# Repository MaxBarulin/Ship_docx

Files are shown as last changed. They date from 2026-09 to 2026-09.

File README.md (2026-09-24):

# «Волжский Горизонт» - колёсное круизное судно мелкой осадки

Проект под конкурсное задание УЖЦ ОСК 2026, редакция 2. Прототип по
технике - ПКС-180 «Золотое кольцо» (колёса в нишах, две жилые палубы);
внешность своя, современная: чёрный корпус, светлая лента главной палубы,
красная линия, графитовый ярус кают.

**Главное правило репозитория:** все числа проекта живут в параметрических
библиотеках `src/lib/`, вся графика и документы собираются скриптами из
`scripts/`. Если число встречается в записке или на плане - оно посчитано,
не набрано. Нашли расхождение между своим документом и библиотекой - права
библиотека; нужна правка - говорите Максу, а не правьте сгенерированный файл.

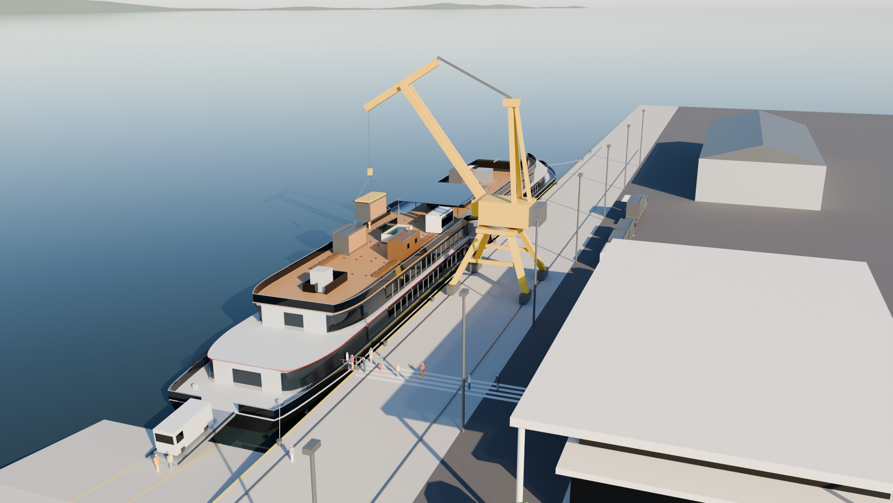
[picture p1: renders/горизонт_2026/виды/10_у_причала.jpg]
Порт приписки: смена модуля краном, сход по трапу и аппарели


---

## 1. Первый час - всем, по порядку

| # | Что открыть | Зачем | Время |
|---|---|---|---|
| 1 | [`renders/горизонт_2026/лист_проекта_горизонт.png`](renders/горизонт_2026/лист_проекта_горизонт.png), папка [`renders/горизонт_2026/виды/`](renders/горизонт_2026/виды/) | как судно выглядит: общий вид, борт, солнечная палуба с модулями, у причала | 5 мин |
| 2 | этот README, разделы 2 и 3 | что должен знать каждый и что смотреть именно вам | 10 мин |
| 3 | [`docs/проект/концепция.md`](docs/проект/концепция.md) | почему судно такое: каждое решение с причиной - это ответы на вопросы жюри | 15 мин |
| 4 | [`docs/сводка_состояние.md`](docs/сводка_состояние.md) | что закрыто по КЗ (15 требований) и по матрице оценки, что открыто по строкам - генерируется | 10 мин |
| 5 | [`docs/проект/записка.md`](docs/проект/записка.md) - оглавление и свой раздел | пояснительная записка по десяти блокам КЗ; незаполненные места помечены **НЕ ЗАПОЛНЕНО** | 10 мин |
| 6 | [`docs/задание/KZ_UZhTs_OSK_2026.md`](docs/задание/KZ_UZhTs_OSK_2026.md) и матрица `docs/задание/Zony_otvetsvennosti_2026_UZhTs.xlsx` | само задание и за что дают баллы | 10 мин |
| 7 | [`docs/план/План_работы_команды_УЖЦ_2026.md`](docs/план/План_работы_команды_УЖЦ_2026.md) | кто за что отвечает, гейты и синки | 5 мин |

## 2. Что должен знать каждый

| Характеристика | Значение |
|---|---|
| Длина × ширина корпуса | **140,0 × 16,5 м**; ширина задана маршрутом, длина - компоновкой |
| Габаритная ширина с колёсами | 16,0 м - колёса утоплены в ниши |
| Высота борта / осадка | 3,00 м / **1,26 м** при 2377 т (расчётная 1,30); КЗ: эксплуатация на глубине 1,5 м - 6,5 км/ч по мели |
| Габаритная высота от ВЛ | 9,9 м, рубка стационарная; самый низкий мост маршрута 13,3 м (Затонские мосты, Уфа) |
| Палубы | второе дно · трюм (нежилой, 2,1 м) · главная · средняя · солнечная (открытая) |
| Пассажиры / экипаж | **208 мест в 64 каютах** четырёх категорий, 12 мест М4 / 48 человек |
| Движитель | два гребных колеса Ø4,90 м на миделе, 12 шарнирных плиц, механизм Моргана |
| Энергетика | гибрид: 3 ГДГ по 600 кВт на **метаноле**, батарея 600 кВт·ч, берег, солнце; автономность 15 суток |
| Автомобили | 4 места класса «Б» до 3,5 т: гараж на главной палубе, кормовая аппарель 9 × 3,6 м |
| Сервисы сверх ресторанов | пять: театр-лаунж, спа и фитнес, детский клуб, панорамный салон, галереи к колёсам |
| Маршрут | кольцо Самара - Казань - Уфа - Самара по Волге, Каме и Белой, 15 дней, 2606 км; класс РКО «О 2,0» |
| Солнечная палуба | 18 слотов под контейнеры 20' HC на **72 фундаментах-замках**, шесть тем «трансформера» до 60 т (запас по заданию Глеба 85 т); смена темы - в Самаре краном порта |
| **Узел КД** | **литой фундамент-замок модуля ВГ-2026.46.00** - решение команды 22.09.2026 |

Решения, которые нельзя перепутать на защите:

- **Узел для КД - литой фундамент-замок** для крепления модулей солнечной
  палубы (решение 22.09.2026, он же по заданию Глеба). В плане команды §7
  ещё прежний узел - ось плицы; от него отказались, его документации в
  репозитории нет.
- **Фундамент литой, литейка своя**: корпус 20ГЛ литьём в форму из ХТС,
  конус-замок 40Х, рычаг 09Г2С, четыре болта М24 А4-80 через изолирующие
  втулки на подкладной лист АМг5. Нагрузки - от качки **этого** судна
  (период и крен - из теории корабля), а не из старого проекта.
- **Осадка:** расчётная 1,30, фактическая по нагрузке масс 1,26; узел
  считан на худший период качки в диапазоне осадок 1,20…1,30.
- **Метанол, а не СПГ:** танк СПГ не встаёт ни в трюм, ни под мосты;
  метанол - в цистернах второго дна, бункеровка автоцистерной на любом причале.
- **Смена модуля у причала** (`gorizont_berth`): судно лагом левым бортом,
  портальный кран 16 т достаёт дальний ряд на вылете 20,3 м; трап и
  аппарель не круче 0,08 - проходимы для кресла-коляски.

## 3. Кому что смотреть первым делом

Роли - по плану команды. «Открыто» - строки матрицы, которые на 22.09 не
закрыты; живой список - `docs/сводка_состояние.md`, раздел 4.

| Кто | Роль по плану | Открыть первым | За вами открыто |
|---|---|---|---|
| **Владимир** | докладчик, чек-лист КЗ (C4) | `docs/сводка_состояние.md` §1 - все 15 требований КЗ сходятся, у каждого место; `python scripts/сверка_требований_КЗ.py` - чек-лист «требование → где закрыто»; `концепция.md` - ответы на «почему»; лист проекта и `виды/` | творческое задание - 5 мемов к 24.09 (2 балла, с Андреем); прогон регламента |
| **Маша** | интеграция, ПЗ, презентация, персонал, риски | `docs/проект/записка.md` целиком - она сводит; разделы 5 и 8; `docs/проект/персонал_и_дорожная_карта.md`; схемы `02б_загрузка_персонала.png`, `03_оргструктура.png`; `docs/команда/README.md` - что из ваших файлов встроено | записка 5.3…5.5 (подбор, оплата, обучение - 2,5); подтвердить оценки и мероприятия реестра рисков (3,5 частично); кооперация по судну (1,5); презентация (3,5); все разделы и вёрстка ПЗ в А4 (2); сквозная проверка «вход → выход» (2) |
| **Лена** | финмодель | записка раздел 6 и 5.3…5.5 - по вашей таблице (`docs/команда/Nash_raschet_shablon.xlsx`), приложение Б - `docs/проект/приложение_Б_экономика.xlsx`, что поправлено - `gorizont_economy.ПРАВКИ`; входы для затрат: трудоёмкость и численность - `персонал_и_дорожная_карта.md`; спецификация узла - `renders/горизонт_2026/чертежи/46_спецификация_лист1…2.png`; мощности, оборудование и программа выпуска узла - `docs/проект/узел_фундамент_twistlock.md` §7…10; нагрузка масс судна - `docs/проект/теория_корабля.md`, А.2 | затраты, себестоимость, цена, выручка, точка безубыточности, окупаемость, NPV/IRR, схема финансирования - около 19 баллов; ставки для `gorizont_build.затраты_на_персонал` |
| **Иван** | рынок, маршрут | записка 1.1 (1.1.2…1.1.5 пусты), 1.1.7 - сегменты уже посчитаны (`gorizont_market`); карта маршрута `схемы/04а_маршрут_карта.png`; замечания к «Маршрутам» - `gorizont_route.ЗАМЕЧАНИЯ` и концепция §8 | объём рынка, объём продаж, конкуренты, маркетинговая стратегия, цены и сеть для ППО - 5,5 балла; стоимость единицы на рынке - с Леной |
| **Глеб** | технология, материалы; модули солнечной палубы | `docs/проект/узел_фундамент_twistlock.md` - ваш «Чертёж крепления» стал узлом КД: материалы §3, литьё и подготовка формы §5, оснастка §6, мощности §7, планировка §9; карты ЕСТД `renders/горизонт_2026/чертежи/46_МК_*, 46_ОК*, 46_КЭ*, 46_ККИ*`; модульное решение - `docs/проект/модульное_решение.md`, листы `CAD/модули/МР-01…03`; кадр `виды/11_смена_модуля.jpg` | сверить принятое: оборудование литейки, загрузку цехов, планировку (2 балла частично); прислать остальные файлы «пачки» креплений - в репозитории только `Чертёж крепления.jpg` |
| **Андрей** | прочность, планировка участка | узел §4 - расчёт по качке судна, 44 проверки; теория корабля `docs/проект/теория_корабля.md` (остойчивость А.3, прочность А.7), листы `CAD/расчёты/РТ-01…09`; планировка `схемы/08_узел_участок.png` | творческое задание (с Владимиром); планировку сверить с цехами верфи |
| **Алексей** | КД узла, работоспособность идеи | СБ и детали: `CAD/узел/ВГ-2026_46_*.dxf` (растр - `renders/горизонт_2026/чертежи_dxf/ВГ-2026_46_*.png`); 3D - `CAD/STEP/VG-2026_46_*.step`; спецификация; рендеры `узел/46_01…03`; эксплуатация - записка раздел 9 | DWG листов узла - `CAD/DWG/узел/` (собраны 23.09); просмотреть КД глазами конструктора |
| **Макс** | 3D, визуализация | `CLAUDE.md` - как устроен репозиторий; `blender/gorizont.blend`; `scripts/blender_*` | взрыв-схема и лист проекта - пересобираются из скриптов; презентационные кадры для Маши |

## 4. Что открыто (43,5 балла из 95 по документам, на 22.09)

| Блок | Баллов | Кто | Что нужно |
|---|---|---|---|
| Экономика и затраты (A, B6) | ≈ 19 | Лена (+ Иван по цене) | финмодель целиком; входы уже есть в библиотеках (см. раздел 3) |
| Персонал: подбор, оплата, обучение (B6) | 2,5 | Маша | записка 5.3…5.5 |
| Риски и кооперация (B2) | 5 частично | Маша | подтвердить оценки реестра рисков; кооперация по судну |
| Рынок (B4) | 5,5 | Иван | записка 1.1.2…1.1.5 |
| Презентация и ПЗ (C1, C2) | 5,5 | Маша | презентация; вёрстка записки в А4 |
| Сквозная связность (B1) | 2 частично | Маша | «вход → выход» после заполнения записки |
| Творческое задание (A) | 2 | Андрей, Владимир | мемы к 24.09 |
| Мощности и планировка узла (B5) | 2 частично | Глеб, Андрей | сверить принятое оборудование и загрузку с данными верфи |

Закрыто 51,5 балла: концепция, дизайн-проект, КД узла, технология и
производство узла, теория корабля, чертежи ОР, модель и визуализация,
требования КЗ (C4).

## 5. Где что лежит

```
docs/задание/            КЗ ред. 2 и матрица оценки - не менять
docs/план/               план и Гант команды - не менять без просьбы
docs/команда/            ваши файлы как получены (байт в байт); что из них встроено - docs/команда/README.md
docs/проект/             концепция, записка, узел КД, модульное решение, теория корабля, персонал и дорожная карта
docs/сводка_состояние.md состояние по КЗ и матрице - генерируется scripts/сводка.py
src/lib/                 параметрические библиотеки: здесь живут все числа (карта - CLAUDE.md)
scripts/                 генераторы: модель, планы, схемы, чертежи, записки, сверки
CAD/                     ОР-01…08, РТ-01…09, МР-01…03, КД узла в DXF; DWG/ - те же в DWG; STEP/, GLB/ - 3D узла
renders/горизонт_2026/   виды, планы, схемы, расчёты, чертежи, узел, каюты, облик - генерируется
blender/gorizont.blend   модель судна с солнечной палубой; собирается с нуля blender_судно.собрать()
```

Картинки для презентации:

| Что | Где |
|---|---|
| судно целиком, борт, корма, нос, вид сверху | `renders/горизонт_2026/виды/01…08_*.jpg` |
| у причала, смена модуля, сход на берег | `renders/горизонт_2026/виды/10_у_причала.jpg`, `11_смена_модуля.jpg`, `12_сход_на_берег.jpg` |
| взрыв-схема судна | `renders/горизонт_2026/виды/09_взрыв_схема.jpg` |
| узел: сборка, взрыв-схема, отливка со стержнем | `renders/горизонт_2026/узел/46_01…03_*.png` |
| интерьеры кают | `renders/горизонт_2026/каюты/00_лист_кают.png` |
| планы палуб | `renders/горизонт_2026/планы/` |
| маршрут, дорожная карта, оргструктура, модули, производство узла | `renders/горизонт_2026/схемы/` |
| чертежи в растре | `renders/горизонт_2026/чертежи_dxf/`, `…/чертежи/` |

## 6. Как пересобрать и проверить

```bash
pip install -r requirements.txt
cd src && python -m lib.gorizont_ga && cd ..      # вместимость и проверки компоновки
python scripts/сверка_требований_КЗ.py             # требования КЗ и матрица оценки
python scripts/сводка.py                           # docs/сводка_состояние.md
python scripts/записка.py                          # docs/проект/записка.md
python scripts/записка_фундамента.py               # docs/проект/узел_фундамент_twistlock.md
```

Остальные проверки и сборка модели в Blender - `CLAUDE.md`.

## 7. Правила для всех

1. Числа - только из библиотек или сгенерированных документов; руками не переписывать.
2. Свои файлы - в `docs/команда/` как есть; Макс встроит их в библиотеки и
   допишет строку в `docs/команда/README.md`.
3. Сгенерированные файлы (`записка.md`, `сводка_состояние.md`, `теория_корабля.md`,
   `узел_фундамент_twistlock.md`, всё в `renders/`) руками не правятся:
   правка пропадёт при следующей сборке. Текст для записки - присылать,
   он встанет в скрипт.
4. `docs/задание/` не менять никогда; `docs/план/` - только по просьбе.

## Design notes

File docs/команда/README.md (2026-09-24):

# Файлы от команды — как получены

Лежат байт в байт (`.gitattributes`: `docs/команда/** -text`), не правятся.
Что из них встроено в проект и что в них надо поправить —
`docs/проект/персонал_и_дорожная_карта.md`; первичная сверка —
`docs/проект/сверка_персонал_и_дорожная_карта.md`.

| Файл | От кого | Получен | Что это | Куда встроено |
|---|---|---|---|---|
| `Raschet_chislennosti_PRIMER.docx` | Лена, Маша | 22.09.2026 | пример расчёта численности по Приказу Минпромторга № 958 на чужое судно 3283 т | методика в `src/lib/gorizont_build.трудоёмкость()`, `численность()`; считается на наше порожнее из `gorizont_hydro` |
| `Org_struktura.docx` | Маша | 22.09.2026 | схема оргструктуры верфи (SmartArt) и справка «проектное бюро или дочерняя компания» | `gorizont_build.оргструктура()` → `renders/горизонт_2026/схемы/03_оргструктура.png`; добавлены ПБ и служба качества с РРР |
| `UZhTs_Dorozhnaya_karta.pdf` | Маша | 22.09.2026 | дорожная карта постройки, первая редакция (MS Project, 42 задачи, 17.09.2026 — 29.09.2028) | заменена редакцией Лены; наши замечания к ней учтены там |
| `солнечная_палуба/` | Глеб | 22.09.2026 | задание по модульным решениям (`Информаци-задание.docx`: площадка 32 × 13 м, запас 85 т, пять тем из 20-футовых контейнеров, twistlock на болтах), 3D узла крепления (`Чертёж крепления.jpg`: платик 09Г2С, палец 40Х), референсы бань, бассейна, офисов и две страницы поставщиков модулей | `src/lib/gorizont_modules.py` → листы `CAD/модули/ВГ-2026_МР-01…03`, `docs/проект/модульное_решение.md`, `схемы/06_модульное_решение.png`; крепление стало **узлом КД** — литой фундамент-замок ВГ-2026.46.00 (`gorizont_twistlock`, `CAD/узел/`, `docs/проект/узел_фундамент_twistlock.md`); в модели — 72 опоры и модули темы, смена модуля у причала (`виды/11_смена_модуля.jpg`) |
| `Маршруты.docx` | маршрутная группа (Иван) | 22.09.2026 | маршрут, редакция 2: программа по дням (Набережные Челны + автобус в Елабугу, ходовой день на Белой) и таблица мостов по плечам с допустимыми высотами | `gorizont_route.ПОРТЫ`, `МОСТЫ` → `МОСТ_МИН` 13,3; замечания к файлу — `gorizont_route.ЗАМЕЧАНИЯ` и концепция §8; карта `схемы/04_маршрут.png`, `маршрут.geojson` |
| `Дорожная_карта_Лена.pdf` | Лена | 22.09.2026 14:56 | дорожная карта постройки, вторая редакция (52 задачи, 22.09.2026 — 22.05.2030, с РКД, Регистром, МТО и закладкой киля) | заменена третьей редакцией; наши четыре замечания к ней учтены там частично |
| `Дорожная_карта_Лена_ред3.pdf` | Лена | 22.09.2026 16:22 | третья редакция (55 задач, сдача 06.06.2030) | заменена четвёртой |
| `Дорожная_карта_Лена_ред4.pdf` | Лена | 23.09.2026 | четвёртая редакция (MS Project, 56 задач, 864 дня, закладка 08.12.2027, спуск 12.09.2028, ходовые 05.10.2029, передача 11.01.2030) | **база** `gorizont_build.ЛЕНА`, страницы как есть - `схемы/02а_дорожная_карта_стр1…2.png`; исправлена опечатка - сервис с 12.01.2030 (в карте 12.01.2035) |
| `Персонал_Маша.docx` | Маша | 23.09.2026 | раздел «Персонал» - оргструктура верфи и проектной группы, схема взаимодействия, расчёт численности по № 958, подбор, оплата труда | на обсуждении, в записку не встроен |
| `правки 23.09.26/ПЗ_УЖЦ_2026.docx` | Маша, Глеб | 23.09.2026 | ПЗ команды: **титульный лист Маши - идёт в записку как есть**; красным - технология узла Глеба (твистлок «ласточкин хвост» из 4 деталей, литьё поз. 1-3, плазма поз. 4, оборудование, две цепочки шагов) | `gorizont_twistlock` (технология, цех в арендованном ангаре, мощности, себестоимость), записка блок 4; остальной текст ПЗ - черновики, не брались |
| `правки 23.09.26/Корпус твистлока (модель, узел).m3d`, `.prt` | Андрей | 23.09.2026 | модель корпуса узла (КОМПАС-3D v22 и NX) | габарит 175 × 160 × 76 мм взят из JT внутри `.prt`; для 3D и чертежей нужен STEP |
| `правки 23.09.26/Корпус твистлока. Отчет 09г2с.html`, `... Отчет Вст3СП5.html` | Андрей | 23.09.2026 | расчёт МКЭ узла в APM FEM (сила 33,1 кН = бассейн 13,5 т на 4 опоры) | заменены отчётом 24.09 из папки `Прочность` |
| `Прочность/Отчет 20ГСЛ.html`, `20ГСЛ Коэф запаса.png`, `20ГСЛ Перемещение 1.png`, `... 2.png` | Андрей | 24.09.2026 | расчёт МКЭ узла в сборе на принятых материалах - корпус 20ГСЛ, платик 09Г2С, запор 40Х, 33,1 кН; запас 3,83 по текучести, 6,93 по прочности, 191,8 МПа, 0,0028 мм | берётся как есть: `gorizont_twistlock.МКЭ`, записка 3.3, 3.4, записка узла 4.2; картинки - рисунки 46_04…06 без дерева и окна КОМПАС (`записка_фундамента.рисунки_мкэ`) |
| `Маша (правки по тексту, очеловечивание).docx` | Маша | 24.09.2026 | новый текст введения, 1.1 абзацы 1-2, первый абзац сегмента рынка, 5.1 абзац 1 | вставлено: `записка.введение()`, `записка_рынок._анализ`, `gorizont_market.ПОЗИЦИОНИРОВАНИЕ` (он же в 1.1.7), `записка.блок5`. Поправлено: «–» и «;» по правилам, «В отличии» → «В отличие», «Новизной ... является в» → «Новизна ... заключается в», «наличие флота» → «нехватка флота», «пары преклонного возраста» → «старшего» (сегмент 45+), «заместитель» → «заместители», «службой» → «службы», «посадка и высадка на протяжении всего маршрута» → «маршрут кольцевой» |
| `Nash_raschet_shablon.xlsx` | Лена | 24.09.2026 | расчёт себестоимости постройки по статьям верфи: материалы, ПКИ, трудоёмкость, ФОТ, ДЗП, взносы, АУП и ИТР, обучение, маркетинг | `gorizont_economy`, записка блок 6 и 5.3…5.5, приложение Б (`docs/проект/приложение_Б_экономика.xlsx`); исправлены ТЗР, единицы кабеля и труб, металл по массе проекта, добавлены ОПР, ОХР, прибыль, НИОКР, безубыточность, окупаемость |
| `правки 23.09.26/Marketing.docx` | Иван | 23.09.2026 | анализ рынка, PEST, SWOT, сегменты, TAM/SAM/SOM, цены, конкуренты, 4P | `gorizont_market`, записка блок 1; пересчитано на 208 мест, 11 рейсов, навигацию май - октябрь, без балконов |

Числа проекта в документах коллег (водоизмещение, сроки, численность)
надо брать из библиотек, а не переписывать руками: см. таблицы сравнения в
`персонал_и_дорожная_карта.md`.

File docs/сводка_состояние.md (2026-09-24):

# Волжский Горизонт - состояние проекта

Собрано `scripts/сводка.py` из живых данных проекта. Руками здесь
не написано ни одного числа - всё считается библиотеками или читается
из файлов задания и из файловой системы.

## 0. Стадии - что сделано и что впереди

| Стадия | Статус | Где |
|---|---|---|
| 1. Проектирование - концепция, компоновка всех уровней, планы палуб и кают | **сделано** | docs/проект/концепция.md, renders/горизонт_2026/планы/ |
| 2. Визуальный концепт в 2D - борт, план, сечения, цвет | **принят (облик v2)** | renders/горизонт_2026/облик/, scripts/облик_2d.py |
| 3. Решения команды - длина 140, облегчённая конструкция, тип плиц, блок C4 | **приняты** | docs/проект/концепция.md, п. 6 |
| 4. Программа снижения массы - алюминий, лёгкая отделка, сталь D36, нагрузка масс по размещению | **сделано** | gorizont_hydro.groups() - трюм и цистерны из gorizont.ТРЮМ/TANKS, дифферент 0,11 м |
| 5а. Модель. Оболочка по облику v2 - корпус, палубы, ярусы, портал, колёса, фальшборты | **сделано** | blender_судно.собрать() - 0 пересечений, 0 щелей, 16,50 м |
| 5б. Модель. Наполнение - переборки, каюты с мебелью, трапы, лифты, трюм по gorizont.ТРЮМ | **сделано** | blender_помещения.py - 1219 объектов, 0 пересечений, 0 щелей |
| 5в. Модель - общественные помещения, проёмы переборок, колодцы трапов, навес модулей, фонарь атриума | **сделано** | src/lib/gorizont_public.py - один источник для планов, DXF и 3D, 6 проверок, в т. ч. путь эвакуации 1,2 м |
| 5г. Модель. Солнечная палуба - 72 фундамента-замка ВГ-2026.46.00 из 3D узла (закрыто под модулем, открыто на свободном слоте), модули темы «президентская» с отделкой по типу | **сделано** | blender_модули.py, входит в blender_судно.собрать(тема=…), 0 пересечений, 0 щелей |
| 5д. Стоянка у причала порта приписки - стенка, пандус под аппарель, трап, швартовы, портальный кран 16 т с модулем на крюке, кадры 10…12 | **сделано** | gorizont_berth (9 проверок - уклоны трапа и аппарели, вылет и груз крана, пронос над соседями), blender_причал.py |
| 6. Узел КД (решение команды 23.09.2026) - фундамент-замок модуля ВГ-2026.46.00, твистлок «ласточкин хвост» из 4 деталей - корпус 20ГСЛ по STEP конструктора, запор-поковка 40Х, стержень, платик 09Г2С, и шайба-подкова. Отчёт МКЭ конструктора на принятых материалах, качка судна, материалы, спецификация | **библиотека сделана, КД и 3D перестраиваются** | gorizont_twistlock (62 проверки, 0 замечаний, модули тяжелее 10 т только в ДП, фундамент 0,077 м в gorizont.py), docs/проект/узел_фундамент_twistlock.md. CAD/узел/, CAD/STEP, GLB, рендеры узла - прежнего литого узла |
| 7. Технология и производство узла - отдельный цех в арендованном ангаре 36 × 24: литейная ветка (корпус), плазменная (платик), мехобработка, сварка, окраска, сборка. Карты ЕСТД, оснастка, оборудование с ценами, загрузка, штат, кооперация, планировка, сроки, себестоимость узла | **сделано** | чертежи/46_*.png, схемы/07…10, 12_узел_*.png. Себестоимость узла - gorizont_twistlock.себестоимость() |
| 8. Пакет визуализации - виды судна с модулями, у причала и смена модуля, взрыв-схема, узел (сборка, взрыв, отливка со стержнем), интерьеры шести типов кают | **сделано** | renders/горизонт_2026/{виды,узел,каюты}/, лист интерьеров каюты/00_лист_кают.png |
| 9. Теория корабля по методике СПбГМТУ - чертёж, ординаты, кривые элементов, строевая и нагрузка, остойчивость, непотопляемость, прочность, ходкость | **сделано** | docs/проект/теория_корабля.md, renders/горизонт_2026/расчёты/01…07 |
| 10. Чертежи общего расположения ОР-01…08 в DXF и DWG (сечения по длине - ОР-08) | **сделано** | CAD/ВГ-2026_ОР-*.dxf, CAD/DWG/ из чертежи_dwg.py (AutoCAD Core Console). Растр renders/горизонт_2026/чертежи_dxf/ |
| 11. Модельный ряд - три версии на одном корпусе | **сделано** | renders/горизонт_2026/схемы/модельный_ряд.png |
| 12а. Персонал и дорожная карта постройки - трудоёмкость по № 958, численность по этапам, оргструктура верфи. Карта - редакция 4 Лены от 23.09.2026 (MS Project), передача 11.01.2030 | **сделано** | gorizont_build.ЛЕНА, docs/проект/персонал_и_дорожная_карта.md, схемы/02…03, исходники коллег - docs/команда/ |
| 12б. Маршрут - 15 дней Самара - Уфа - Самара (редакция 2 от 22.09.2026 - Набережные Челны с автобусом в Елабугу, ходовой день на Белой, таблица мостов - предел 13,3 м), путь по фарватеру для приложения, карта на спутнике, целевая аудитория и сегментация | **сделано** | gorizont_route, gorizont_market, схемы/04_маршрут.png и 04а_маршрут_карта.png, docs/проект/маршрут.geojson, записка 1.1.7 |
| 12в. Документы по матрице - объём рынка, конкуренты, стратегия, экономика, риски, подбор/оплата/обучение, записка | **сделано** | рынок - gorizont_market (Ваня), экономика - gorizont_economy по расчёту Лены, приложение Б - docs/проект/приложение_Б_экономика.xlsx |
| 14. Рубка стационарная (мосты от 13,3). Модульное решение солнечной палубы по заданию Глеба - 18 слотов 20-футовых, 72 фундамента-замка ВГ-2026.46.00 (корпус 20ГСЛ, запор 40Х), 6 тем «трансформера», среды, монтаж | **сделано** | gorizont_modules, CAD/модули/ВГ-2026_МР-01…03 (+DWG), docs/проект/модульное_решение.md, схемы/06_модульное_решение.png |
| 13. Творческое задание - 5 мемов к 24.09.2026 | **не начато** |  |
| 15. Солнечная палуба - обмер, допускаемая нагрузка, площадки под модули | **сделано** | gorizont_deckload, docs/проект/солнечная_палуба_нагрузка.md, схемы/05_солнечная_палуба.png |

## 1. Минимальные требования конкурсного задания

| Требование | Значение | Норма | |
|---|---|---|---|
| Пассажирских кают | 64 | по расстановке ГА | ок |
| Пассажирских мест | 208 | >= 200 по КЗ | ок |
| Минимальная площадь каюты, м2 | 8.5 | >= 8 по КЗ | ок |
| Категорий кают | 4 | 4 по КЗ | ок |
| Мест группы М4 | 12 | >= 11 (5 % от 208) | ок |
| Мест для автомобилей | 4 | >= 4 по КЗ | ок |
| Автономность, суток | 15 | >= 15 по КЗ | ок |
| Габарит с колёсами, м | 16.0 | <= 16,0 | ок |
| Габаритная высота, м | 9.9 | <= 13.30 | ок |
| Модуль на солнечной палубе под мостом, м запаса | 2.52 | >= 0 (мост 13.3, модуль 2.98) | ок |
| Скорость на глубине 1,5 м, км/ч | 6.5 | <= 9.0 (Fnh <= 0.65) | ок |
| Запас под килём на фарватере 1,5 м стоя, м | 0.24 | >= 0.20 при осадке 1.26 | ок |
| Фактическая осадка к расчётной, м | 1.26 | <= 1.30 | ок |
| Доп. культурно-развлекательных сервисов | 5 | >= 3 по КЗ | ок |
| Обязательных систем описано | 7 | 7 по КЗ | ок |

Сходится всё 15 из 15.

## 2. Проверки модели

| Узел | Проверка | Значение | | Примечание |
|---|---|---|---|---|
| Надстройка | Панели фасада - главная | 0.00 шт | ок | перекрытий 0, за ярусом 0 |
| Надстройка | Панели фасада - средняя | 0.00 шт | ок | перекрытий 0, за ярусом 0 |
| Надстройка | Ярус не выходит за борт | -1.00 м | ок | худшая точка x=13.0, главная - 7.25 при борте 8.25 |
| Надстройка | Бортовой проход на главной палубе | 1.00 м | ок | путь эвакуации вдоль борта, норма 0.90 м |
| Надстройка | Ширина в свету на средней палубе | 13.10 м | ок | под ряд 3.00 каюта + 1.30 коридор + 2.25 внутренняя, два борта |
| Надстройка | Площадь средней палубы | 1356.80 м² | ок | под каютный блок |
| Надстройка | Зазор колеса до внутренней щеки кожуха | 0.20 м | ок | щека кожуха она же переборка атриума |
| Надстройка | Зазор колеса до наружной кромки борта | 0.25 м | ок | колесо не выходит за габарит 16,0 м |
| Надстройка | Зазор колеса до подволока кожуха | 0.29 м | ок | от верха механизма до листа кожуха |
| Надстройка | Средняя палуба над кожухом | 0.13 м | ок | перекрытие кожуха - настил средней палубы |
| Надстройка | Поля вокруг арки кожуха | 1.00 м | ок | круг R 2.03 с рамкой - до торца щеки 2.75, до подволока 0.42 |
| Надстройка | Зазор обшивки кожуха до колеса по всей высоте | 0.17 м | ок | худшая точка x=63.5, z=3.00 |
| Гребное колесо | Плица в воде близка к отвесу | 9.80 ° | ок | вход 9.8°, низ 0.3°, выход -8.6°, у радиальной было бы 46° |
| Гребное колесо | Плица наверху откинута наружу | 146.90 ° | ок | иначе висит внутрь колеса, к ступице |
| Гребное колесо | Механизм без рывков | 2.12 °/° | ок | макс. поворот плицы на 1° поворота колеса |
| Гребное колесо | Верх колеса с механизмом под кожухом | 5.55 м | ок | зазор до средней палубы 0.25 м |
| Гребное колесо | Габарит с колёсами | 16.00 м | ок | колесо утоплено в нишу на 0.25 м |
| Гребное колесо | Кривошип не задевает соседние оси | 0.23 м | ок |  |
| Гребное колесо | Плица не ниже основной плоскости | 0.75 м | ок | нижняя кромка плицы на 0.75 м выше киля - на фарватере 1,5 м колесо не должно быть первым, что коснётся дна |
| Гребное колесо | Частота вращения | 23.70 об/мин | ок | окружная 6.08 м/с |
| Гребное колесо | Плиц в воде одновременно | 2.61 шт | ок | дуга 92.1° |
| Компоновка | Пассажиров | 208.00 чел | ок | 64 кают, по категориям - стандарт 28/100, эконом 24/84, бизнес 6/12, люкс 6/12 |
| Компоновка | Мест М4 | 12.00 чел | ок | 6 кают М4, норма 5 % от 208 |
| Компоновка | Категорий кают | 4.00 шт | ок | эконом, стандарт, бизнес, люкс |
| Компоновка | Глубина внутренней каюты на средней палубе | 2.25 м | ок | в свету 13.10 минус бортовая 3.00 и коридор 1.30 |
| Компоновка | Минимальная площадь каюты | 8.50 м² | ок | КЗ п. 6 |
| Компоновка | Мест экипажа | 48.00 чел | ок | 16 кают экипажа |
| Компоновка | Путь до второго трапа | 34.50 м | ок | от любой каюты, два независимых пути |
| Компоновка | Трап-холлы выровнены по палубам | 1.00  | ок | кормовой и носовой на одних абсциссах |
| Компоновка | Зоны не перекрываются | 0.00 шт | ок |  |
| Компоновка | Ресторан в две смены | 148.00 мест | ок | 222 м² по 1,5 м² на место |
| Компоновка | Театр-лаунж | 93.00 мест | ок | 112 м² |
| Компоновка | Доп. сервисов кроме магазинов и ресторанов | 5.00 шт | ок | Театр-лаунж с лекторием, Спа и фитнес, Детский и подростковый клуб с творческой мастерской, Панорамный салон-обсерватория, Галереи к гребным колёсам - машина, которую видно |
| Управляемость и мелководье | Разворот на месте - колёса + водомёт | 4.80 мин на 360° | ок | пара колёс 1554 кН·м на плече 12.8 м, водомёт 32 кН на плече 63 м |
| Управляемость и мелководье | Нос против ветра 10 м/с у шлюза | 2048.00 кН·м | ок | ветер 43 кН на парусности 869 м², держим водомётом и разнотягом |
| Управляемость и мелководье | Скорость на глубине 1.5 м | 7.50 км/ч | ок | просадка 0.13 м, под килём 0.11 м при осадке 1.26 |
| Управляемость и мелководье | Запас под килём на 1.5 м с просадкой | 0.11 м | ок | на скорости 7.5 км/ч |
| Управляемость и мелководье | Тормозной путь реверсом с полного хода | 174.00 м | ок | 71 с, норма практики - не больше трёх длин |
| Узел КД - фундамент-замок | Голова проходит отверстие фитинга «открыто» | 104.00 мм | ок | голова 104 × 54 в отверстии 124.5 × 63.5 |
| Узел КД - фундамент-замок | Голова держит «закрыто» | 20.20 мм | ок | лепесток за кромкой отверстия шириной 63.5 |
| Узел КД - фундамент-замок | Центратор входит в отверстие фитинга | 1.75 мм | ок | центратор 60 × 116, зазор 1.75 и 4.25 на сторону |
| Узел КД - фундамент-замок | Голова над днищем фитинга | 2.00 мм | ок | центратор 30 мм, днище фитинга 28 мм - свободный ход вверх |
| Узел КД - фундамент-замок | Стержень в полости и прорези | 14.00 мм | ок | полость 15 мм по высоте, прорезь 16, поворот в секторе 80° |
| Узел КД - фундамент-замок | Отрыв берёт шайба, а не стержень | 0.70 мм | ок | стержень до свода полости 0.7 мм, шайба до низа корпуса 0.3 мм - шайба садится первой |
| Узел КД - фундамент-замок | Шайба в проточке вала | 12.60 мм | ок | проточка Ø22 длиной 12.6, шайба 12 мм, разрез 22.5 |
| Узел КД - фундамент-замок | Шайба ставится снизу через окно платика | 55.00 мм | ок | окно 110 × 60 внутри опорных полос (X ±61.7), конец вала на 4.4 мм выше низа платика |
| Узел КД - фундамент-замок | Овалы платика - расстояние до края | 35.50 мм | ок | 4 овала 26 × 45 в точках X ±135, Y ±95, длинная ось по Y |
| Узел КД - фундамент-замок | Шайба болта не заходит на шов | 12.50 мм | ок | шайба Ø50 у болта, катет шва 10 |
| Узел КД - фундамент-замок | Болты мимо стенки подпалубной балки | 135.00 мм | ок | ось X корпуса - поперёк судна, болты в 135 мм от линии балки, пояс 130 |
| Узел КД - фундамент-замок | Высота опоры = высота фундамента в данных судна | 0.08 м | ок | хвост 46 + платик 20 + прокладка 3 + лист 8 мм |
| Узел КД - фундамент-замок | Масса модели - против отчёта МКЭ | 24.20 кг | ок | корпус 7.55 по 3D, платик 14.93, запор 1.45, стержень 0.15, шайба 0.12, расхождение -1.3 % |
| Узел КД - фундамент-замок | Центр тяжести по высоте - против МКЭ | -39.03 мм | ок | платик под полосами хвоста, Z -66…-46 |
| Узел КД - фундамент-замок | Расчётный модуль - самый тяжёлый из тем | 13.50 т | ок | бассейн 13.5 т, как в расчёте МКЭ, в темах - бар, бассейн, детский, клуб, люкс, офис, спа |
| Узел КД - фундамент-замок | Не ставится на фундаменты - вне тем | 0.00 шт | ок | бассейн глубокий - 18 т, в темы не входит, нагрузка на опору выше расчётной |
| Узел КД - фундамент-замок | Нагрузка МКЭ = вес модуля на четыре опоры | 33.10 кН | ок | 13.5 т × 9,81 / 4 |
| Узел КД - фундамент-замок | Порог правила размещения ниже предела по МКЭ | 10.00 т | ок | модули тяжелее 10 т - только в ряду ДП. В бортовом ряду запас 1,25 держится до 12.8 т |
| Узел КД - фундамент-замок | Корпус и платик - напряжение по МКЭ (эксплуатация) | 150.90 МПа | ок | запас 1.17, сжатие 65.0 кН против 33.1 в отчёте МКЭ, запас по текучести 20ГСЛ 1.95 при нужном 1.67 |
| Узел КД - фундамент-замок | Корпус и платик - напряжение по МКЭ (предельный) | 205.70 МПа | ок | запас 1.14, сжатие 88.5 кН против 33.1 в отчёте МКЭ, запас по текучести 20ГСЛ 1.43 при нужном 1.25 |
| Узел КД - фундамент-замок | Корпус и платик - напряжение по МКЭ (посадка) | 230.80 МПа | ок | запас 1.02, сжатие 99.3 кН против 33.1 в отчёте МКЭ, запас по текучести 20ГСЛ 1.28 при нужном 1.25 |
| Узел КД - фундамент-замок | Шов корпуса с платиком, катет 10 (эксплуатация) | 17.00 МПа | ок | запас 6.07, длина 726 мм, толщина 7.0, сдвиг на высоте 61 мм над платиком |
| Узел КД - фундамент-замок | Болт М24 А4-80 - растяжение (эксплуатация) | 306.50 МПа | ок | запас 1.57, затяжка 106 кН (0,5σт), внешняя 9.1 кН на болт, χ = 0.25 |
| Узел КД - фундамент-замок | Стык - нераскрытие (эксплуатация) | 21.20 кН | ок | запас 4.68, остаток затяжки 99 кН не меньше 0,2 затяжки |
| Узел КД - фундамент-замок | Сдвиг платика - держит трение (эксплуатация) | 50.60 кН | ок | запас 1.66, μ = 0.20 по стеклотекстолиту, 4 болта, минус отрыв |
| Узел КД - фундамент-замок | Платик 09Г2С у болта - изгиб (эксплуатация) | 36.70 МПа | ок | запас 5.31, консоль 37.5 мм от шва до болта, толщина 20, ширина 140 |
| Узел КД - фундамент-замок | Балка Т 260 × 8 / 130 × 12 АМг5 - изгиб (эксплуатация) | 52.10 МПа | ок | запас 1.44, пролёт 2.20 м между рамными бимсами, сила в середине, заделка по концам, W = 524 см³ |
| Узел КД - фундамент-замок | Шов корпуса с платиком, катет 10 (предельный) | 32.80 МПа | ок | запас 4.12, длина 726 мм, толщина 7.0, сдвиг на высоте 61 мм над платиком |
| Узел КД - фундамент-замок | Болт М24 А4-80 - растяжение (предельный) | 314.50 МПа | ок | запас 1.53, затяжка 106 кН (0,5σт), внешняя 20.5 кН на болт, χ = 0.25 |
| Узел КД - фундамент-замок | Стык - нераскрытие (предельный) | 21.20 кН | ок | запас 4.27, остаток затяжки 91 кН не меньше 0,2 затяжки |
| Узел КД - фундамент-замок | Болт М24 - срез при проскальзывании (предельный) | 63.40 МПа | ок | запас 4.35, трения 81 кН не хватает - сдвиг на болты через втулки, овалы поперёк сдвига |
| Узел КД - фундамент-замок | Втулка изолирующая - смятие (предельный) | 66.60 МПа | ок | запас 1.65, втулка в листе АМг5 и настиле, 14 мм |
| Узел КД - фундамент-замок | Платик 09Г2С у болта - изгиб (предельный) | 82.30 МПа | ок | запас 3.16, консоль 37.5 мм от шва до болта, толщина 20, ширина 140 |
| Узел КД - фундамент-замок | Балка Т 260 × 8 / 130 × 12 АМг5 - изгиб (предельный) | 52.10 МПа | ок | запас 1.92, пролёт 2.20 м между рамными бимсами, сила в середине, заделка по концам, W = 524 см³ |
| Узел КД - фундамент-замок | Конус-голова 40Х - смятие днища фитинга (предельный) | 14.70 МПа | ок | запас 20.55, две площадки 20.2 × 44 за кромками отверстия 63.5 |
| Узел КД - фундамент-замок | Конус-голова - изгиб лепестка (предельный) | 74.00 МПа | ок | запас 6.38, плечо 26.9 мм от вала, сечение 54 × 23 |
| Узел КД - фундамент-замок | Вал поз. 3 - растяжение по отверстию (предельный) | 91.40 МПа | ок | запас 5.16, Ø30 с поперечной резьбой М14, 287 мм² |
| Узел КД - фундамент-замок | Вал поз. 3 - растяжение по проточке (предельный) | 69.00 МПа | ок | запас 6.84, проточка Ø22 под шайбу, 380 мм² |
| Узел КД - фундамент-замок | Бурт вала - срез (предельный) | 63.30 МПа | ок | запас 4.29, цилиндр Ø22 высотой 6 мм |
| Узел КД - фундамент-замок | Шайба поз. 5 - смятие буртом вала (предельный) | 116.60 МПа | ок | запас 3.06, кольцо Ø30/22.5 без разреза, 225 мм² |
| Узел КД - фундамент-замок | Шайба поз. 5 - срез по кромке отверстия корпуса (предельный) | 30.50 МПа | ок | запас 4.91, цилиндр Ø30 без разреза, толщина 12 |
| Узел КД - фундамент-замок | Шайба поз. 5 - изгиб кольца (предельный) | 108.50 МПа | ок | запас 2.40, бурт на радиусе 13.1, опора на корпус на радиусе 20.2 |
| Узел КД - фундамент-замок | Низ корпуса 20ГСЛ - смятие шайбой (предельный) | 26.40 МПа | ок | запас 12.27, кольцо Ø50/31 вокруг отверстия, 995 мм² |
| Узел КД - фундамент-замок | Центратор - смятие о стенку отверстия фитинга (предельный) | 39.90 МПа | ок | запас 8.11, плоская грань 93.5 мм на высоте 24 |
| Узел КД - фундамент-замок | Настил АМг5 под изолирующей шайбой - смятие (эксплуатация) | 71.90 МПа | ок | запас 1.56, затяжка на шайбу Ø50/25 |
| Узел КД - фундамент-замок | Стержень поз. 2 Ø14 - изгиб при повороте (эксплуатация) | 111.40 МПа | ок | запас 3.18, рука - 300 Н на конце, плечо 100 мм от вала |
| Узел КД - фундамент-замок | Стержень поз. 2 - смятие в отверстии вала (эксплуатация) | 16.40 МПа | ок | запас 32.32, момент 34 Н·м парой сил по длине отверстия Ø30 |
| Узел КД - фундамент-замок | Стержень поз. 2 Ø14 - изгиб при повороте (предельный) | 371.20 МПа | ок | запас 1.27, встали на рукоятку - 1000 Н на конце, плечо 100 мм от вала |
| Узел КД - фундамент-замок | Стержень поз. 2 - смятие в отверстии вала (предельный) | 54.80 МПа | ок | запас 11.85, момент 115 Н·м парой сил по длине отверстия Ø30 |
| Узел КД - фундамент-замок | Прибыли питают отливку | 0.53 кг | ок | две прибыли 37 × 125 × 60 на плече, модуль 14.8 при нужном 14.5 |
| Узел КД - фундамент-замок | Модуль прибыли | 14.80 мм | ок | тепловой узел 12.1 мм, 1,2 модуля отливки 10.1 |
| Узел КД - фундамент-замок | Выход годного | 57.90 % | ок | металла на форму 26.1 кг на две отливки |
| Узел КД - фундамент-замок | Верхняя опока вмещает отливку с прибылью | 136.00 мм | ок | прибыль от плеча, над ней 30 мм смеси |
| Узел КД - фундамент-замок | Платики - из одного листа | 78.00 шт | ок | лист 1500 × 6000, 5 × 15 и 3 в остатке, использование 81 % |
| Узел КД - фундамент-замок | Планировка - зоны в ангаре и не пересекаются | 1.00 м | ок | ангар 36 × 24, под зонами 446 м² (52 %) |
| Узел КД - фундамент-замок | Главный проезд между ветками | 5.00 м | ок | от ворот въезда до ворот выезда |
| Узел КД - фундамент-замок | Мощность цеха в пределах подключения | 206.00 кВт | ок | установленная 342 кВт, одновременность 0.6 |
| Узел КД - фундамент-замок | Узкое место - загрузка за срок серии | 50.70 % | ок | Стол вибрационный формовочный 1,0 × 1,0 м |
| Узел КД - фундамент-замок | Штат покрывает трудоёмкость серии | 92.20 % | ок | 8 человек, серия 12 раб. дней, литьё 8 дней |
| Узел КД - фундамент-замок | Серия - после испытаний установочной партии | 29.10.2027  | ок | акт РКО до начала серии |
| Узел КД - фундамент-замок | Фундаменты готовы до установки на судне | 231.00 раб. дн. | ок | отгрузка 22.11.2027, установка с 10.10.2028 |
| Узел КД - фундамент-замок | Себестоимость - статьи сходятся | 6887223.00 руб. | ок | за штуку 89444 руб. |
| Общественные помещения | Мебель внутри зон и обшивки | 0.00 шт | ок |  |
| Общественные помещения | Мебель без пересечений | 0.00 пар | ок |  |
| Общественные помещения | Мебель вне шахт трапов и лифтов | 0.00 шт | ок |  |
| Общественные помещения | Путь эвакуации 1.20 м через каждое помещение | 0.00 из 7 | ок |  |
| Общественные помещения | Ресторан - мест за столами в одну смену | 108.00 мест | ок | две смены на 208 пассажиров |
| Общественные помещения | Театр-лаунж - сидячих мест | 68.00 мест | ок | плюс бар и стоячие |
| Постройка и персонал | Формула воспроизводит пример коллег | 742339.00 чел·ч | ок | D = 3283 т - t_уд 158 против 158, серийное 571030 против 570585 |
| Постройка и персонал | Доли видов работ | 100.00 % | ок | середины диапазонов прил. 1 дают 97.0 %, остаток разложен поровну |
| Постройка и персонал | Производство после договора | 232.00 дней | ок | первая производственная задача 10.1 - 14.10.2027, договор 24.02.2027 |
| Постройка и персонал | Работы на стапеле не раньше закладки киля | 57.00 дней | ок | 10.4 с 03.02.2028, закладка 08.12.2027 |
| Постройка и персонал | Формирование корпуса кончается до спуска | 0.00 дней | ок | 10.4.1 до 12.09.2028, спуск 12.09.2028 |
| Постройка и персонал | Стапельный период | 7.30 мес | ок | 03.02.2028 - 12.09.2028 |
| Постройка и персонал | Срок поставки длинноцикловых позиций | 9.40 мес | ок | 8.4 - 205 рабочих дней, ГДГ, ГЭД, колёса с приводами - 8…12 месяцев |
| Постройка и персонал | Длинноцикловые позиции до конца стапеля | 61.00 дней | ок | даже при поставке 12 месяцев от 07.2027 - к 07.2028, стапель до 09.2028 |
| Постройка и персонал | Ходовые испытания в навигацию | 10.00 месяц | ок | 14 - 05.10.2029 - 15.10.2029 |
| Постройка и персонал | Ходовые после устранения замечаний по швартовным | 1.00 дней | ок | 13 до 04.10.2029, 14 с 05.10.2029 |
| Постройка и персонал | Акт после устранения замечаний | 18.00 дней | ок | устранение до 22.11.2029, акт с 10.12.2029 |
| Постройка и персонал | Перегон в Самару к открытию навигации | 124.00 дней | ок | судно передано заказчику 11.01.2030, перегон по внутренним путям с открытием навигации около 15.05.2030, первый сезон 2030 |
| Постройка и персонал | Пиковая численность ниже примера коллег | 230.00 чел | ок | у нас порожнее 1966 т против 3283 т, пик в 09.2028 |
| Маршрут | Запас под самым низким мостом | 3.40 м | ок | Затонские мосты (Уфа) 13.3 м (таблица мостов, 15 позиций), габарит 9.90 м со стационарной рубкой |
| Маршрут | Программа укладывается в автономность | 15.00 сут | ок | 15 дней тура при автономности 15 суток |
| Маршрут | Ходовое время по маршруту | 6.20 сут | ок | 2606 км при 17.5 км/ч - 149 ч хода на 15 дней, остальное стоянки |
| Маршрут | Расписание сходится - приходы не позже плановых дней | 0.00 опозданий | ок | самый поздний приход - Тольятти, день 1 23:02 |
| Маршрут | Путь по фарватеру построен | 1.00  | ок | docs/проект/маршрут.geojson из scripts/маршрут.py |
| Маршрут | Дни программы идут подряд | 0.00 разрывов | ок | каждый следующий порт - на день после конца стоянки |
| Целевая аудитория | Все типы кают отнесены к сегменту | 0.00 типов | ок | без сегмента - - |
| Целевая аудитория | Доли сегментов складываются в 100 % | 100.00 % | ок | по местам в каютах |
| Целевая аудитория | Рейсов в навигацию | 11.00 рейсов | ок | 184 суток навигации / 16 суток оборота |
| Целевая аудитория | Сегмент М4 не меньше нормы КЗ | 12.00 мест | ок | шесть кают М4 |
| Целевая аудитория | Цены заданы для всех типов кают | 0.00 типов | ок | шесть типов |
| Целевая аудитория | Цена растёт от эконома к люксу | 275000.00 руб. | ок | эконом < стандарт < бизнес < люкс |
| Целевая аудитория | Полный круиз не дороже суток × 15 | 0.00 типов | ок | скидка полного круиза 0,0…2,6 % |
| Целевая аудитория | Загрузка в пределах 0…100 % | 85.00 % | ок | вход маркетинга |
| Целевая аудитория | Путёвок не больше мест × рейсов | 1944.00 путёвок | ок | 208 мест × 11 рейсов |
| Целевая аудитория | Доли продаж по сегментам - 100 % | 100.00 % | ок | по путёвкам |
| Целевая аудитория | Выручка за рейс = цены × места | 30752000.00 руб. | ок | полная загрузка, по каютам расстановки |
| Целевая аудитория | Выручка за навигацию = цены × проданные места | 287392000.00 руб. | ок | расхождение -139 200 руб. - округление путёвок до целых |
| Целевая аудитория | SOM покрывает продажи | 2041.00 путёвок | ок | план продаж - 95,2 % SOM |
| Целевая аудитория | Балконов в данных нет | 0.00 упоминаний | ок | бортовые каюты с панорамным остеклением |
| Солнечная палуба | Пластина настила держит норму | 17.90 кПа | ок | 6 мм АМг5 при шпации 0.55 м - 17.9 кПа против 5.0 |
| Солнечная палуба | Запас массы до расчётной осадки | 89.00 т | ок | T 1.256 → 1.30 при TPC 20.4 т/см |
| Солнечная палуба | Модулей в расчётной осадке по нормам РКО | 16.00 шт | ок | по 4.3 т, ЦТ на 1.53 м над настилом, парусность стенок учтена |
| Солнечная палуба | Дифферент с модулями | 0.13 м | ок | модули у миделя, ЦВ ватерлинии x = 66.6 |
| Солнечная палуба | Свободная высота под мостом | 5.50 м | ок | мост 13.3, модуль с фундаментом 2.98 |
| Модульное решение | Слотов на двух площадках | 18.00 шт | ок | А - 12, Б - 6, фундаментов 72 |
| Модульное решение | Проход между рядами и у борта | 1.25 м | ок | три ряда на ширине 13.33 м - между рядами 1.76, у борта 1.25, торцевой 1.2 |
| Модульное решение | Один ярус под мостом | 2.97 м | ок | второй ярус не проходит - 5.9 > 5.5 |
| Модульное решение | Предел массы по заданию против запаса по осадке | 85.00 т | ок | 85 т задания не выходят за 89 т до расчётной осадки 1.30 |
| Модульное решение | Тема «базовая» | 0.00 т | ок | 0 мод., T 1.256, K 31.7, 0 кВт из 502 на стоянке, y ЦТ 0.00, опора - сжатие 0, отрыв 0 кН |
| Модульное решение | Тема «деловая» | 33.00 т | ок | 9 мод., T 1.272, K 21.7, 56 кВт из 502 на стоянке, y ЦТ 0.53, опора - сжатие 24, отрыв 4 кН |
| Модульное решение | Тема «оздоровительная» | 60.40 т | ок | 9 мод., T 1.286, K 21.4, 92 кВт из 502 на стоянке, y ЦТ 0.29, опора - сжатие 65, отрыв 0 кН |
| Модульное решение | Тема «детская» | 34.20 т | ок | 10 мод., T 1.273, K 21.0, 35 кВт из 502 на стоянке, y ЦТ 0.52, опора - сжатие 24, отрыв 4 кН |
| Модульное решение | Тема «событийная» | 31.80 т | ок | 8 мод., T 1.272, K 22.5, 44 кВт из 502 на стоянке, y ЦТ 0.08, опора - сжатие 24, отрыв 4 кН |
| Модульное решение | Тема «президентская» | 36.40 т | ок | 6 мод., T 1.274, K 24.1, 45 кВт из 502 на стоянке, y ЦТ 0.54, опора - сжатие 65, отрыв 0 кН |
| Модульное решение | Модули тяжелее 10 т - только в ряду ДП | 0.00 шт | ок | в темах: бассейн 13.5 т - во всех темах в ДП |
| Модульное решение | Узел крепления ВГ-2026.46.00 - проверки | 0.00 шт | ок | 62 проверок узла (качка, прочность, литьё, цех, сроки), SWL опоры - сжатие 100, отрыв 10, сдвиг 55 кН |
| Качка и успокоительные цистерны | Настройка цистерны на период качки | 3.35 с | ок | расхождение 0.0 % при допуске 5 % |
| Качка и успокоительные цистерны | Масса жидкости от водоизмещения | 3.51 % | ок | для заметного гашения нужно не менее 1 % |
| Качка и успокоительные цистерны | Метацентрическая высота с учётом свободной поверхности | 15.48 м | ок | норма РКО для пассажирских судов 0,5 м |
| Автономное управление | Дистанция начала манёвра | 300.00 м | ок | тормозной путь 174 м плюс 126 м за время реакции |
| Автономное управление | Потребная дальность обнаружения | 601.00 м | ок | двойной запас к дистанции начала манёвра |
| Автономное управление | Дальность АИС к потребной | 66.60 раз | ок | АИС даёт 40 км при потребных 0.6 км |
| Автономное управление | Время на встречное расхождение | 62.00 с | ок | скорость сближения 9.7 м/с |

## 3. Что лежит в репозитории

| Артефакт | Файлов | Закрывает |
|---|---|---|
| Модель судна (`blender/gorizont.blend`) | 1 | B5, C3 |
| 2D-облик - борт, план, сечения (`renders/горизонт_2026/облик`) | 4 | B3, C3 |
| Внешние виды (рендеры) (`renders/горизонт_2026/виды`) | 15 | C3 |
| Интерьеры шести типов кают, лист интерьеров (`renders/горизонт_2026/каюты`) | 19 | КЗ п.5, C3 |
| Планы палуб (`renders/горизонт_2026/планы`) | 6 | КЗ п.5, B5 |
| Схемы систем (`renders/горизонт_2026/схемы`) | 20 | B5 |
| Чертежи на листах (`renders/горизонт_2026/чертежи`) | 15 | B5 |
| Чертежи ОР-01…08 в DXF (`CAD/ВГ-2026_ОР-*.dxf`) | 8 | B5 |
| Чертежи ОР в DWG (AutoCAD Core Console) (`CAD/DWG/ВГ-2026_ОР-*.dwg`) | 8 | B5 |
| Листы РТ-01…09 теории корабля в DXF из данных (`CAD/расчёты`) | 9 | КЗ п.12, B5 |
| То же в DWG (`CAD/DWG/расчёты`) | 9 | КЗ п.12, B5 |
| Листы МР-01…03 модульного решения в DXF (`CAD/модули`) | 3 | КЗ доп. п.3, B5 |
| То же в DWG (`CAD/DWG/модули`) | 3 | КЗ доп. п.3, B5 |
| Модульное решение солнечной палубы - слоты, фундамент, темы (`docs/проект/модульное_решение.md`) | 1 | КЗ доп. п.3 |
| Схема модульного решения для презентации (`renders/горизонт_2026/схемы/06_модульное_решение.png`) | 1 | КЗ доп. п.3 |
| 3D узла в STEP (`CAD/STEP`) | 11 | B5 |
| 3D узла ВГ-2026.46.00 в glTF для модели судна (`CAD/GLB`) | 3 | B5, C3 |
| Узел - сборка, взрыв-схема, отливка со стержнем (`renders/горизонт_2026/узел`) | 6 | B5, C3 |
| КД узла ВГ-2026.46.00 - СБ, корпус, отливка ЛФ, плита модельная, ящик стержневой (`CAD/узел/ВГ-2026_46_*.dxf`) | 10 | B5 |
| То же в DWG (`CAD/DWG/узел/ВГ-2026_46_*.dwg`) | 10 | B5 |
| Узел КД - твистлок «ласточкин хвост», МКЭ и качка, материалы, технология, цех, себестоимость (`docs/проект/узел_фундамент_twistlock.md`) | 1 | B5 |
| Пояснительная записка (`docs/проект/записка.md`) | 1 | B1, B5 |
| Расчёты по теории корабля (`docs/проект/теория_корабля.md`) | 1 | КЗ п.12, B5 |

## 4. Матрица оценки - 100.0 балла

| Раздел | Есть | Частично | Не начато | На площадке | Итого |
|---|---|---|---|---|---|
| A Работа команды, творческое задание и строки без шапки раздела в файле | 12.00 | 0.00 | 3.00 | 0.00 | 15.00 |
| B1 Целостность проекта | 0.00 | 2.00 | 0.00 | 0.00 | 2.00 |
| B2 Управление сроками и рисками проекта | 1.50 | 5.00 | 0.00 | 0.00 | 6.50 |
| B3 Привлекательность и перспективность идеи | 3.50 | 0.00 | 0.00 | 0.00 | 3.50 |
| B4 Маркетинговая составляющая в проекте | 8.50 | 1.00 | 0.00 | 0.00 | 9.50 |
| B5 Управление техническим содержанием проекта | 24.00 | 4.50 | 0.00 | 0.00 | 28.50 |
| B6 Управление персоналом в проекте | 14.75 | 0.75 | 1.00 | 0.00 | 16.50 |
| C1 Навыки представления информации заказчику | 0.00 | 0.00 | 3.50 | 5.00 | 8.50 |
| C2 Системность отображенной информации в проекте | 0.00 | 2.00 | 0.00 | 0.00 | 2.00 |
| C3 Визуализация проекта | 4.00 | 0.00 | 0.00 | 0.00 | 4.00 |
| C4 Выполнение требований заказчика | 4.00 | 0.00 | 0.00 | 0.00 | 4.00 |
| **ВСЕГО** | **72.25** | **15.25** | **7.50** | **5.00** | **100.00** |

Документами закрывается 95.0 балла из 100.0 - 5.0 не зависит от нас и оценивается на площадке. **Закрыто 72.2, частично 15.2, не начато 7.5.**

Записка - 13 разделов, 108635 знаков, незаполненных мест 0.

### Что открыто по строкам матрицы (22.8 балла)

| Раздел | Строка | Критерий | Балл | Состояние | Что есть / чего нет |
|---|---|---|---|---|---|
| A | 24 | Выполнено творческое задание | 1.00 | **нет** | мемы не сделаны, срок 24.09.2026 |
| A | 27 | Креативность выполнения творческого задания | 1.00 | **нет** | мемы не сделаны |
| A | 71 | Корректность и обоснованность расчета финансовых потоков на ППО | 1.00 | **нет** | финпотоки ППО не считаны |
| B1 | 78 | Совпадение входов и выходов по каждому блоку | 2.00 | частично | библиотеки связаны, сводка и концепция сходятся, в записке 0 незаполненных мест -  |
| B2 | 87 | Корректно обозначены риски проекта | 1.50 | частично | реестр из 9 рисков - gorizont_build.риски(), записка 8, оценки ПБ, подтверждение Маши |
| B2 | 92 | (строка без названия) | 1.50 | частично | схема кооперации по узлу есть (схемы/07_узел_кооперация.png), по судну - нет |
| B2 | 88 | Минус 0,5, если нет цифровой оценки рисков | 1.00 | частично | вероятность и ущерб 1…5, оценка - произведение (принято) |
| B2 | 90 | Минус 0,5 если отсутствуют антирисковые мероприятия для критичных риск | 1.00 | частично | мероприятие у каждого риска - записка 8 |
| B4 | 133 | Корректность программы ППО | 1.00 | частично | записка 9.3 - гарантия верфи 522 рабочих дня, ЗИП, сервис в Самаре, цен и сети нет - Иван |
| B5 | 140 | Разработан чертеж детали/узла | 1.50 | частично | КД нового узла по STEP корпуса и библиотеке gorizont_twistlock. СБ и детали в CAD/узел/ - прежнего литого узла, перевыпускаются по новой геометрии |
| B5 | 141 | Разработана 3D модель детали/узла | 1.00 | частично | STEP корпуса от конструктора (docs/команда/правки 23.09.26/Korpus_tvistloka_model_uzel.stp), 3D сборки перестраивается по gorizont_twistlock (запор, стержень, платик) |
| B5 | 142 | Соответствие чертежа и 3D модели детали/узла | 1.00 | частично | геометрия корпуса в gorizont_twistlock снята со STEP, масса модели 24,2 кг против 24,52 в МКЭ. Чертежи и 3D сборки - после перестройки |
| B5 | 168 | Корректность чертежа детали/узла | 1.00 | частично | СБ, деталь, ЛФ по ЕСКД - прежнего узла, перевыпускаются |
| B6 | 241 | Схема финансирования и срок возврата заемных средств/инвестиций | 1.00 | **нет** | схемы финансирования нет |
| B6 | 221 | Разработаны методы подбора персонала, определены источники | 0.75 | частично | записка 5.3 - штат под проект, оклады по вакансиям, сроки формирования группы. Процедуры отбора нет |
| C1 | 251 | Логичность, структурированность представления материалов | 2.00 | **нет** | презентации нет |
| C1 | 248 | Оформление презентации | 1.50 | **нет** | презентации нет |
| C2 | 266 | В пояснительной записке присутствуют все разделы | 1.00 | частично | десять блоков КЗ и приложение А, 0 незаполненных мест -  |
| C2 | 267 | Оформление пояснительной записки | 1.00 | частично | требования к оформлению в шапке, вёрстка в А4 с колонтитулами не сделана |

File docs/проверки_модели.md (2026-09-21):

# Проверки модели: что ловим и чем

> **Методики верны, числа — нет.** Проверки написаны под сцену и от
> конкретного судна не зависят, поэтому переезжают на колёсный проект
> как есть. А вот нормы («пересечений 0, дыр 18 точек») снимались с
> прежней модели, которой на этой ветке больше нет. Новые нормы
> устанавливаются заново, когда будет построена новая сцена.

Брак, который видно на рендерах — висящие кресла в театре, «летающие» столы в
ресторане и носовом салоне, щели в корпусе, пустой план первой палубы, —
пролезал мимо проверок по одной причине: они работали на уровне *объектов*, а
брак живёт на уровне *кусков сетки*. Мебель зала — одна сетка на зал, и один
улетевший стул в габарите 18 × 11 м не виден ни габаритом, ни центром масс, ни
пересечениями.

Ниже — проверки, каждая закрывает свой класс ошибок. Все живут в
`scripts/blender_аудит.py`, кроме двух последних.

## 1. Опора — `support()`

Сетка режется на связные куски. Кусок стоит законно, если под ним в пределах
60 мм начинается другой кусок, чей верх доходит до его низа: палуба, помост,
ступень, ножка, тумба. Дополнительно засчитывается навеска — переборка ближе
80 мм сбоку — и подвес к подволоку.

Лучами это не берётся: низ сиденья лежит ровно на верхе ножки, и луч из точки
внутри ножки выходит уже под палубой. Поэтому сравниваются габариты кусков, а
не пересечения лучей.

Что поймала: 4 столешницы носового салона без единой ножки, кресла театра на
ножках, начинающихся в воздухе, полки и зонты, висящие без кронштейнов.
Было 3032 куска, стало 0.

## 2. Кресло на ходулях — `stilts()`

Сиденье со стороной 0,42…0,62 м, поднятое над палубой выше 0,80 м. Подъём
рядов в зале делают ступенями помоста; если ряд подняли, удлинив ножки, каждое
кресло стоит на двух палках над пустым полом — в кадре ряды «взлетают».
Барные табуреты уже по габариту и в проверку не идут.

Было 256, стало 0: помост в театре теперь строится вместе с креслами, и ряды
привязаны к ступеням — ни одно кресло не встаёт на стык двух отметок.

## 3. Стул повёрнут от стола — `seating()`

Сиденье — плоский кусок 0,35…0,62 м на высоте 0,36…0,52 м над палубой;
спинка — узкий кусок рядом и выше. Взгляд сидящего идёт от спинки к сиденью;
столешница обязана лежать в этом полупространстве не дальше 0,80 м от кромки
сиденья.

Было 168, стало 0. Стул теперь и не может отвернуться: он создаётся только
через `chair(..., facing)`, а направление задаётся из центра стола.

## 4. Проход к месту — `circulation()` в `gorizont_rooms.py`

Зал растрируется сеткой 100 мм на высоте бедра. Занятая клетка — деталь,
стоящая на полу и выше 0,30 м: помост, ковёр и танцпол проход не
перекрывают, по ним ходят; подвес, экран и полка над головой — тоже нет.

Просветов два, а не один. Магистраль зала меряется по 1,20 м: по ней
расходятся на посадку и уходят по тревоге. Подход к своему месту — по
0,50 м: между спинками соседних стульев протискиваются, и требовать там
1,20 м значит выкинуть половину посадки.

Что поймала: в ресторане при шаге 2,05 × 2,10 м между группами оставалось
0,11 м, и со 110 мест из 144 было не встать; в театре при шаге рядов 0,95 м
между спинкой и следующим сиденьем оставалось 0,49 м. Шаг ресторана
2,40 м, ступень театра 2,00 м на два ряда с шагом 1,00 м — мест без подхода
не осталось ни в одном зале.

## 5. Замкнутость помещения — `enclosure()`

Из точек внутри каждой закрытой зоны на высоте глаз веер из 72 лучей в
горизонт и один вверх. Луч, ушедший дальше габарита судна, значит дыру.
Пробные точки ставятся по измеренной полуширине, а не по ширине судна: точка
в 6,9 м от диаметрали в носу оказывается снаружи обвода, и тогда «дыру»
показывает любое помещение.

Что поймала: остекление главной палубы обрывалось на 128,05 м при полосе окон
до 130,40 м, кормовые переборки надстройки перекрывали 5,8 м из тринадцати.
Дыры закрывает `scripts/blender_ограждение.py` — полосами по обводу цоколя и
торцевыми щитами. Было 32 точки с потерей до 41 луча, стало 18 точек по
одному-два луча: это волосяные стыки между деталями, а не проёмы.

## 6. Не пустой план — `_plan_filled()` в `blender_рендер_планов.py`

План режется плоскостью отсечения камеры (`clip_start = h − 2,05`), а не
скрытием объектов: у палубного настила минимум по z лежит на днище, и скрыть
его как объект нельзя — он и закрывал первую палубу сверху. После рендера
считается доля непрозрачных пикселей; меньше 8 % — план пуст, и это печатается
в отчёт.

Тот же скрипт снимает планы Workbench-ом с плоским светом и без теней: тени от
солнца забивали планы и выжигали палубу.

## 7. Выноски не наезжают — `collisions()` в `схемы_разрезы.py`

Все подписи складываются в список прямоугольников до отрисовки, и после сборки
схемы список проверяется на пересечения. Отметки палуб ушли в левое поле, а
ватерлиния и габаритная высота — в правое: между 1,40 и 2,22 м всего 13 px, и
в одном поле они неизбежно налезали друг на друга. Строка выноски подбирается
так, чтобы её линия не перечеркнула подпись в строке ближе к модели.

## 8. Пересечения и обвод — `pairs()`, `outside_hull()`

Как было: BVH, чётность лучей, глубина 25 мм. Ничего за обводом и за
надстройкой. Сейчас 0 пар.

## 9. Контактный лист — `blender_контактный_лист.py`

Каждое помещение тремя кадрами 640 px: от кормовой переборки вдоль зала, от
носовой обратно и планом сверху. Лист снимается Workbench-ом за десяток
секунд, и смотреть на него можно все помещения разом. Один «красивый» рендер
стоит полторы минуты и показывает один угол — именно этого шага и не хватало.

## 10. Кадр — `_autofit()` в `blender_рендер_видов.py`

На общем виде и у набережной корма уходила за край кадра: фокусное
подбиралось на глаз. Теперь точки габарита судна проецируются в кадр через
`world_to_camera_view`, и объектив ужимается, пока самая дальняя не войдёт с
запасом 5 %. Крупные планы носа и кормы подгонке не подлежат — там судно в
кадр и не должно влезать целиком.

## 11. Числа в документах — `scripts/сверка_документов.py`

Записка и сверка с описанием пишутся руками, и числа в них устаревают молча:
класс сменили с «О» на «М», посадку пересчитали по проходам, а в документах
остались прежние значения. Скрипт берёт факты из библиотек и из счёта модели
и ищет в документах противоречащие им написания. Проверяются утверждения о
модели, а не цитаты описания: в левой колонке сверки класс «О» стоит
законно — так написано у Алексея.

## Порядок прогона

`support` → `stilts` → `seating` → `circulation` → `enclosure` → правка →
`pairs` → контактный лист глазами → чистовые рендеры → `seats` →
`сверка_документов`.

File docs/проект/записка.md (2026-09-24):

# Пояснительная записка

## ВОЛЖСКИЙ ГОРИЗОНТ. Колёсное круизное судно мелкой осадки

Команда **УЖЦ ОСК 2026**. Конкурсное задание по компетенции «Управление
жизненным циклом изделия», чемпионат АО «ОСК» 2026 года, редакция 2.

Редакция от 24.09.2026. Все числа записки получены расчётом по единой
параметрической модели судна и пересчитываются при изменении исходных
данных.

> **Требования к оформлению при вёрстке в PDF** (приложение к КЗ):
> формат А4, шрифт не менее 11, ГОСТ Р 2.105, сквозная нумерация страниц,
> не более 100 страниц. Внизу каждой страницы:
> «№ блока. Наименование блока. УЖЦ ОСК 2026. Номер страницы (по порядку).»
> Номер и наименование блока - слева, наименование команды - по центру,
> номер страницы - справа.

---

## Введение

Речной туризм в России имеет значительный потенциал для дальнейшего развития: обширная сеть рек и каналов, богатое историко-культурное наследие прибрежных городов, растущий интерес к внутренним путешествиям. Это и многое другое создают благоприятные условия для развития круизных путешествий.

В последние годы внутренний туризм демонстрирует устойчивый рост, а потребители всё чаще выбирают форматы отдыха, которые сочетают комфорт и возможность увидеть уникальные уголки нашей страны.

Туристическая необходимость проекта определяется несколькими факторами:

1) Необходимость оформления визовых документов для заграничных круизов ведёт к увеличивающемуся спросу на прогулки по рекам и озёрам в рамках нашей страны.
2) Развитие речного транспорта может способствовать экономическому подъёму прибрежных территорий, так как увеличивается загрузка экскурсионных бюро, активируется малый бизнес, улучшается качество гостиничных услуг.
3) Речные маршруты способствуют раскрытию туристического потенциала небольших городов, которые не всегда доступны от крупных транспортных узлов, но легко достижимы для посещения по воде.

Новизна данного проекта заключается в комплексном подходе к проектированию судна, который адаптируется под специфику рек и озёр Российской Федерации.

В отличие от универсальных решений, судно разрабатывается с учётом ограничений осадки и габаритов для возможности прохода по мелководью, по узким каналам, под мостами, особенно в черте городов.

Также учитывается планировка общественных пространств для высокого уровня комфорта и доступности - продуманная эргономика, зоны для маломобильных пассажиров, развитая инфраструктура и цифровые решения. С учётом этого проект можно считать востребованным.

Таким образом, проект направлен на создание современного, экономически эффективного судна, которое не только будет способно удовлетворить растущий спрос на речной туризм, но и станет примером сбалансированного решения, учитывающего технические, экологические и социальные аспекты развития водного транспорта в России. Поэтому проектирование и создание судна «Волжский Горизонт» является необходимостью для нашей страны, учитывая, что 2026 год объявлен Президентом Годом единства народов России.

## 1 Маркетинговая документация

### 1.1 Анализ рынка

В связи с тем, что рынок речных круизов в России растёт, порог входа на него становится выше. Именно поэтому новое пассажирское судно для такого типа рынка будет стоить дорого, а строиться несколько лет. По данным Минтранса, в 2025 году пассажирские перевозки речным транспортом выросли на 7 % и достигли 13 млн человек, а туристические перевозки выросли на 28 %. Сдерживающим фактором является нехватка флота, так как спрос растёт быстрее, чем обновляются суда. Рассмотренные суда-аналоги на Волге и Каме построены в 1957 и 1973 годах (1.1.6).

Основные клиенты речных круизов - семьи с детьми, пары старшего возраста, молодёжь, маломобильные пассажиры с сопровождающими, а также заказчики фрахта и корпоративных выездов. Факторами будущего роста являются развитие внутреннего туризма, государственная поддержка судостроения, переход на экологичное топливо (метанол, гибридные установки) и недостаток предложений в формате «река + автомобиль» на малых реках.

Внешние факторы разобраны PEST-анализом (политические, экономические, социально-культурные и технологические факторы):

Таблица 1

| Группа факторов | Фактор | Что это значит для проекта |
|---|---|---|
| Политические | Государственная поддержка внутреннего туризма и обновления речного флота | Спрос на новые суда и маршруты, доступ к мерам поддержки |
|  | Меры поддержки постройки судов с экологичными энергетическими установками | Метанол и гибридная установка отвечают этому направлению |
|  | Ужесточение экологических требований | Очистка и повторное использование сточных вод, ход на батарее в черте городов |
| Экономические | Курс рубля и ограничения выездного туризма | Спрос переходит на внутренние маршруты |
|  | Рост цены дизельного топлива | Метанол и береговое питание снижают зависимость от дизельного топлива |
|  | Устойчивый платёжеспособный спрос на каюты высокого класса | Каюты бизнес и люкс, а на солнечной палубе - президентская тема модулей |
| Социально-культурные | Совмещение работы и отдыха в поездке | Деловая тема модулей - кабинеты и переговорные на солнечной палубе |
|  | Рост значения инклюзивного туризма | 12 мест М4, 4 лифта |
|  | Интерес к этнотуризму | Казань и Уфа на маршруте, программа о татарской и башкирской культуре |
| Технологические | Метанольные двигатели и гибридные энергетические установки | 3 ГДГ на метаноле по 600 кВт и аккумуляторная батарея |
|  | Солнечные модули и накопители энергии на судах | Солнечные модули 24 кВт над атриумом |
|  | Колёсный движитель для мелководья | КПД колеса 0,68 при осадке 1,26 м |

Сильные и слабые стороны проекта, возможности и угрозы рынка сведены в SWOT-анализ (сильные стороны, слабые стороны, возможности, угрозы):

Таблица 2

| Сильные стороны (S) | Слабые стороны (W) |
|---|---|
| S1. Модульная солнечная палуба - 6 тем на 18 слотах, тема меняется за смену | W1. Высокая стоимость постройки нового судна |
| S2. Осадка 1,26 м - Белая до Уфы и перекаты Камы всю навигацию | W2. Длительный срок окупаемости |
| S3. Гараж на 4 автомобиля класса «Б» - формат «река + автомобиль» | W3. Сезонность - навигация 184 суток, май - октябрь, зимой стоянка |
| S4. Гибридная установка - метанол, батарея, солнечные модули | W4. Нет известной марки на старте продаж |
| S5. 12 мест М4 и 4 лифта |  |
| **Возможности (O)** | **Угрозы (T)** |
| O1. Рост внутреннего туризма - туристические перевозки речным транспортом выросли на 28 % в 2025 году | T1. Повторение решений проекта - колёсного хода и мелкой осадки - другими операторами |
| O2. Государственная поддержка экологичного флота | T2. Экономическая нестабильность и снижение платёжеспособного спроса |
| O3. Формат «река + автомобиль» у речных круизных судов не представлен | T3. Ограничения поставок импортных комплектующих |
| O4. Рост инклюзивного туризма | T4. Изменение и ужесточение норм для судов на метаноле |
| O5. Развитие инфраструктуры метанольного топлива | T5. Дальнейшее обмеление рек |

Перекрёстная матрица SWOT-анализа даёт четыре стратегии:

Таблица 3

|  | Возможности (O) | Угрозы (T) |
|---|---|---|
| **Сильные стороны (S)** | **Стратегия S-O, рост.** Колёсный ход и метанол - основание для участия в программах поддержки экологичного флота (S4, O2). Гараж - вход в нишу автотуризма (S3, O3). Каюты М4 и лифты - предложение для инклюзивного туризма (S5, O4). | **Стратегия S-T, защита.** Осадка 1,26 м - запас на обмеление рек (S2, T5). Метанол, батарея и береговое питание снижают зависимость от цены дизельного топлива (S4, T2). Модульные темы меняют продукт без переоборудования судна, если конкуренты повторят формат (S1, T1). |
| **Слабые стороны (W)** | **Стратегия W-O, развитие.** Субсидии и льготное финансирование экологичного флота снижают стоимость постройки и срок окупаемости (W1, W2, O2). Партнёрство с поставщиками метанола на маршруте, бункеровка автоцистерной у причала (O5). Рост внутреннего туризма - время строить марку через выставки и партнёров (W4, O1). | **Стратегия W-T, удержание.** Смена модульной темы за смену под спрос сезона и фрахт судна целиком в межсезонье (W3, T2). Раннее бронирование со скидкой снижает риск незагрузки рейса (W2, T2). Отечественные комплектующие там, где они есть, - при выборе поставщиков (W1, T3). |

**Вывод по анализу рынка.** Рынок речных круизов растёт, а предложение ограничено числом и возрастом судов. Проект опирается на государственную поддержку экологичного флота, мелкую осадку и формат «река + автомобиль». Слабые места - стоимость постройки и срок окупаемости, их закрывают меры поддержки и гибкость продукта.

#### 1.1.1 Сегмент рынка

Маршрут круиза проходит через три реки с заходом в город Уфа по реке Белой. Мелкая осадка 1,26 м открывает Белую и перекаты Камы, куда крупный круизный флот не сможет пройти. Маршрут кольцевой, посадка и высадка пассажиров происходят в одном порту. На судне присутствуют гараж на четыре автомобиля и шесть кают М4, а в дизайне превалирует современный облик вместо ретро-стилизации.

Сегмент - речные круизы на 10…15 суток по Волге, Каме и Белой с посадкой и высадкой в Самаре. Ценовой уровень семейный (четырёхместные каюты стандарт и семейные) с бизнес- и люкс-каютами для пар 45+. Технический признак сегмента - осадка не более 1,26 м и проход под мостами высотой 13,3 м - маршруты, закрытые для судов с осадкой свыше 2,5 м, и Белая до Уфы, куда крупный круизный флот не заходит.

Сегменты пассажиров выделены по типам кают, которые они занимают. Запрос каждого сегмента и функции судна, которые на него отвечают:

Таблица 4

| Сегмент | Каюты, доля мест | Запрос потребителя | Требуемые функции |
|---|---|---|---|
| Семьи с детьми школьного возраста | стандарт, семейная, 76,9 % | Семейный отдых без перелётов, каникулы на воде. Готовый продукт - проживание, питание, экскурсии и анимация без отдельной организации. Экскурсии по выбору, а не по жёсткому расписанию, выбор порта окончания круиза. Безопасность и досуг детей на борту. | Четырёхместные каюты - стандарт у борта и семейные внутри. Детский и подростковый клуб, творческая мастерская, детская тема модулей на солнечной палубе. Семейные тарифы, дети до 12 лет бесплатно на верхних местах. Онлайн-конструктор экскурсий в портах стоянок. Ограждения, мягкое покрытие игровых зон, медпункт. |
| Пары 45+ и путешественники старшего возраста | бизнес, люкс, 11,5 % | Неспешный отдых, тишина и качество, а не скорость. Музеи, исторические и купеческие города, местная кухня. Свобода в выборе досуга и экскурсий. Высокий уровень сервиса. | Каюты бизнес 15 м² и люкс 18 м² с панорамным остеклением во всю ширину каюты. Ресторан в две смены, бар-лаунж. Спа с сауной, хаммамом и процедурными, фитнес, панорамный салон-обсерватория. Экскурсионная программа в 10 портах маршрута. |
| Компании друзей и молодёжь | эконом, 5,8 % | Доступный совместный отдых на 15 дней. Общение, вечерние программы, музыка. Свобода в выборе экскурсий и порта окончания круиза. | Каюты эконом - внутренние двухместные со световодом и виртуальным окном. Театр-лаунж, вечером клуб, бар-лаунж, открытые палубы. Событийная тема модулей на солнечной палубе - клуб, кино, дискотека. Групповые тарифы, раннее бронирование. |
| Маломобильные пассажиры с сопровождающими | стандарт М4, 5,8 % | Отдых без барьеров. Каюты, оборудованные с учётом потребностей людей с инвалидностью. Выбор удобного порта окончания круиза. | 12 мест в 6 каютах стандарт М4 - круг разворота 1,5 м, душ без порога. 4 лифта на 3 трап-холлах, двери в свету не менее 0,90 м. Телескопический трап и кормовая аппарель. Путь эвакуации 1,2 м, медпункт, обученный персонал. Адаптированные экскурсии по выбору. |

**Вывод по сегментам.** Ядро продукта - семьи с детьми, 76,9 % мест. Их дополняют пары старшего возраста (11,5 %), которым важны комфорт и культурная программа, и маломобильные пассажиры с сопровождающими (5,8 %), для которых решает доступность. Компании друзей и молодёжь (5,8 %) занимают каюты эконом и добирают загрузку в начале и в конце навигации. Экскурсии с отдельной оплатой и выбор порта окончания круиза отвечают запросу всех сегментов на свободу выбора. Численность сегментов, география и каналы продаж - 1.1.7, ёмкость рынка - 1.1.2, суда-аналоги - 1.1.6.

#### 1.1.2 Объём рынка

Объём рынка оценён в три ступени - TAM (общий объём рынка), SAM (доступный объём рынка) и SOM (достижимая доля нового оператора). Счёт идёт в пассажирах в год, одна путёвка - один пассажир. База оценки - около 750 000 пассажиров речных круизов в 2025 году, около 6 % от 13 млн пассажиров речного транспорта. Сегменты 2 и 3 оценены по возрастной структуре 200 000 пассажиров круизов, сегмент 4 - от числа людей с инвалидностью в России. Доли сегментов в базе и доли целевых клиентов - оценка ПЭУ.

База сегментов 1…3 уже в пассажирах, число групп (заказов) получено делением на число мест в каюте сегмента. В сегменте 4 база - люди с инвалидностью, каждый едет с сопровождающим, и пассажиров вдвое больше, чем групп. Расчёт объёма рынка:

Таблица 5

| Сегмент | База оценки | Потенциальных клиентов | Доля целевых, % | Ёмкость, пассажиров в год | Групп (заказов) |
|---|---|---|---|---|---|
| Семьи с детьми школьного возраста | 25 % от 750 000 пассажиров речных круизов 2025 года | 187 500 пассажиров | 80 | 150 000 | 37 500 по 4 человека |
| Пары 45+ и путешественники старшего возраста | 54 % от 200 000 пассажиров круизов, возраст 45 лет и старше | 108 000 пассажиров | 10 | 10 800 | 5400 по 2 человека |
| Компании друзей и молодёжь | 14 % от 200 000 пассажиров круизов, возраст 18…40 лет | 28 000 пассажиров | 5 | 1400 | 700 по 2 человека |
| Маломобильные пассажиры с сопровождающими | 11 000 000 людей с инвалидностью в России | 11 000 000 человек | 0,005 | 1100 | 550 по 2 человека |
| **TAM** - общий объём рынка | сумма сегментов |  |  | **163 300** | 44 150 |
| **SAM** - доступный объём рынка | 25 % TAM - маршрут в одном регионе, Волга, Кама и Белая |  |  | **40 825** |  |
| **SOM** - достижимая доля | 5 % SAM - консервативная доля нового оператора |  |  | **2041** |  |

В деньгах по средневзвешенной цене путёвки 147 846 руб. (1.1.4) доступный объём рынка SAM - 6,04 млрд руб. в год, достижимая доля SOM - 301,8 млн руб. План продаж судна - 1944 путёвки за навигацию (1.1.3) - занимает 95,2 % SOM и 4,8 % SAM (рисунок 1). Одному судну не нужна доля рынка больше консервативной оценки для нового оператора.

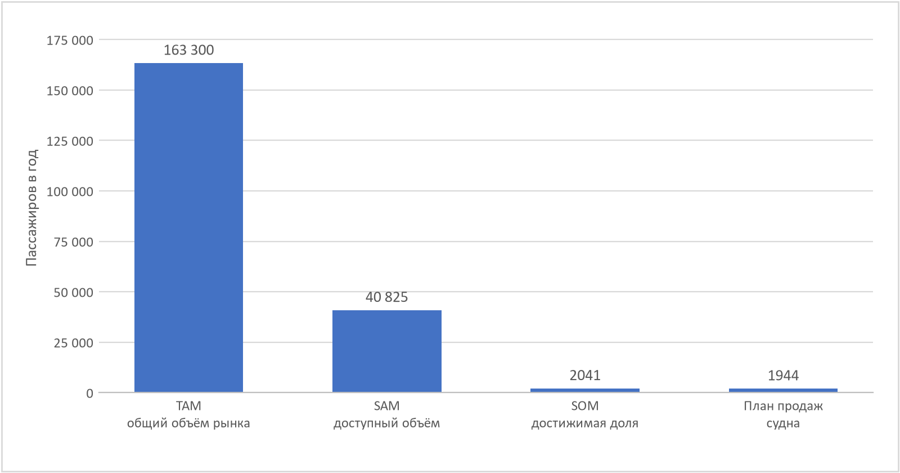
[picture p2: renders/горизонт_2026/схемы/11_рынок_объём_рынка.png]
Объём рынка TAM, SAM, SOM и план продаж судна


Рисунок 1 - Объём рынка TAM, SAM, SOM и план продаж судна

#### 1.1.3 Объём продаж в сегменте

Объём продаж считается в путёвках - одна путёвка на одного пассажира на полный круиз 15 суток - от мест в каютах по общему расположению и числа рейсов за навигацию. Плановая загрузка 85 % - оценка ПЭУ:

Таблица 6

| Показатель | Значение |
|---|---|
| Пассажирских мест на судне | 208 |
| Рейсов за навигацию (184 суток, оборот 16 суток) | 11 |
| Мест за навигацию | 2288 |
| Плановая загрузка | 85 % |
| **Продано путёвок за навигацию** | **1944** |
| Доля плана в SOM, достижимой доле рынка | 95,2 % |
| Доля плана в SAM, доступном объёме рынка | 4,8 % |
| Доля плана в TAM, общем объёме рынка | 1,2 % |

Продажи по сегментам (рисунок 2):

Таблица 7

| Сегмент | Каюты | Мест за навигацию | Продано путёвок | Доля продаж, % | Доля в ёмкости сегмента, % |
|---|---|---|---|---|---|
| Семьи с детьми школьного возраста | стандарт, семейная | 1760 | 1496 | 77,0 | 1,0 |
| Пары 45+ и путешественники старшего возраста | бизнес, люкс | 264 | 224 | 11,5 | 2,1 |
| Компании друзей и молодёжь | эконом | 132 | 112 | 5,8 | 8,0 |
| Маломобильные пассажиры с сопровождающими | стандарт М4 | 132 | 112 | 5,8 | 10,2 |
| **Итого** |  | 2288 | **1944** | 100 |  |

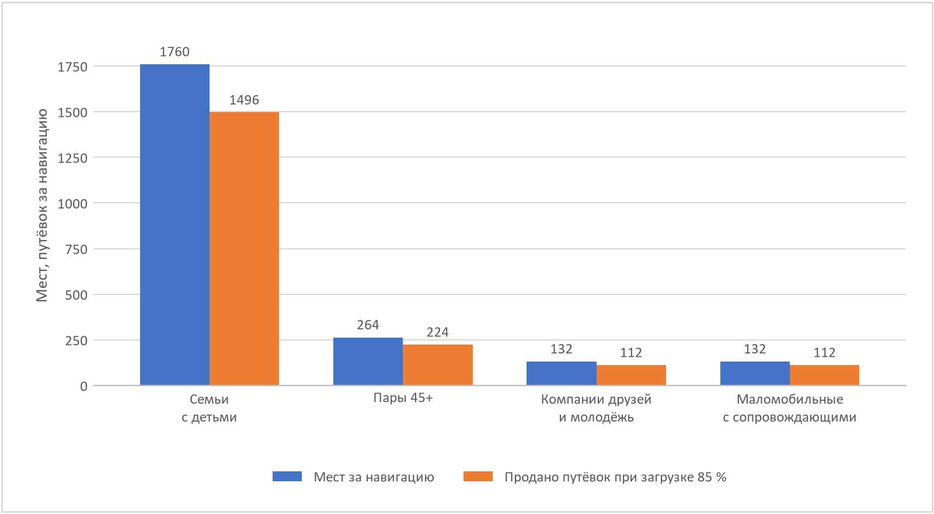
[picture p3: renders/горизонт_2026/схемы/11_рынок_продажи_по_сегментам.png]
Продажи путёвок по сегментам за навигацию


Рисунок 2 - Продажи путёвок по сегментам за навигацию

Основной объём продаж - семьи с детьми, 77,0 % путёвок, это ядро продукта. Пары старшего возраста, молодёжь и маломобильные пассажиры дают остальные 23,0 % и поддерживают загрузку в начале и в конце навигации. Малые сегменты требуют большей доли своей ёмкости - до 10,2 % против 1,0 % у семей, поэтому каюты эконом и М4 открыты для продажи всем сегментам. Объём продаж в штуках - 1944 путёвки за навигацию. Доступный объём рынка SAM в 21 раз больше плана продаж одного судна.

#### 1.1.4 Ориентировочная стоимость единицы изделия

Для пассажира единица продукта - путёвка на круиз 15 суток. Цены по типам кают - оценка ПЭУ по ценам аналогов, число кают и мест - по общему расположению:

Таблица 8

| Тип каюты | Каюта | Кают / мест | Круиз 15 суток, руб./чел. | Сутки при неполном рейсе, руб./чел. | Выручка за рейс при полной загрузке, руб. |
|---|---|---|---|---|---|
| Люкс | бортовая двухместная 18 м², панорамное остекление | 6 / 12 | 275 000 | 18 500 | 3 300 000 |
| Бизнес | бортовая двухместная 15 м², панорамное остекление | 6 / 12 | 200 000 | 13 500 | 2 400 000 |
| Стандарт | бортовая четырёхместная 12 м², два нижних и два верхних откидных места, панорамное остекление | 22 / 88 | 140 000 | 9500 | 12 320 000 |
| Стандарт М4 | бортовая двухместная 18 м² для группы мобильности М4, панорамное остекление | 6 / 12 | 126 000 | 8400 | 1 512 000 |
| Семейная | внутренняя четырёхместная 11,9…14,2 м² с перегородкой, световод и виртуальное окно | 18 / 72 | 140 000 | 9500 | 10 080 000 |
| Эконом | внутренняя двухместная 8,5 м², световод и виртуальное окно | 6 / 12 | 95 000 | 6500 | 1 140 000 |
| **Итого** |  | 64 / 208 |  |  | **30 752 000** |

По категориям КЗ цена круиза на человека - эконом 95 000 руб., стандарт 140 000 руб., бизнес 200 000 руб., люкс 275 000 руб. Каюта стандарт М4 - 126 000 руб., семейная четырёхместная - по цене стандарта. Цена суток при неполном рейсе - для пассажира, который садится или сходит в промежуточном порту, например в Казани или Уфе. Полный круиз дешевле 15 таких суток на 0…2,6 %.

**Средневзвешенная цена путёвки** - 147 846 руб. за круиз 15 суток, 9856 руб. в сутки. Это выручка рейса при полной загрузке 30 752 000 руб., делённая на 208 мест, и цена продукта для пассажира.

Для заказчика единица изделия - судно. Ориентировочная цена головного судна - 2554,0 млн руб. без НДС и 3115,8 млн руб. с НДС, серийные строятся по той же цене с меньшей себестоимостью (6.1, 6.2).

Дополнительные услуги оплачиваются отдельно:

Таблица 9

| Услуга | Цена | Примечание |
|---|---|---|
| Гараж, автомобиль класса «Б» | 30 000 руб. за автомобиль на рейс | Всегда отдельно, 4 места |
| Экскурсии | 2 500…6 000 руб./чел. | По выбору пассажира, онлайн-конструктор |
| Спа-процедуры | 3 000…8 000 руб. | Прайс-лист на борту |
| Модули солнечной палубы | 2 500 руб./ч | Кроме президентской темы |

Цены сопоставлены с ценами аналогов на Волге и Каме. Цены аналогов - оценка ПЭУ, наша цена суток - цена круиза, делённая на 15 суток:

Таблица 10

| Судно или круиз | Маршрут | Суток | Цена, руб./чел. | Цена суток, руб. | Наша каюта, руб. в сутки | Сравнение цены суток |
|---|---|---|---|---|---|---|
| «Александр Невский» | Самара - Волгоград | 8 | 51 500…66 800 | 6438…8350 | эконом 6333, стандарт 9333 | Эконом дешевле на 2…24 %, стандарт дороже на 12…45 % |
| «Принцесса Анабелла» | Самара - Уфа - Казань | 10…12 | от 137 000 | от 11 417…13 700 | стандарт 9333 | Стандарт дешевле на 18…32 % |
| «Игорь Стравинский» | премиальный круиз | 15 | 214 000 | 14 267 | бизнес 13 333 | Бизнес дешевле на 6,5 % |
| «Дягилевская Пермь» | премиальный круиз | 10…12 | от 235 000 | от 19 583…23 500 | люкс 18 333 | Люкс дешевле на 6…22 % |

Эконом по цене суток на уровне нижней цены «Александра Невского», стандарт дороже его, но на 18…32 % дешевле «Принцессы Анабеллы». Бизнес и люкс дешевле премиальных круизов. Круиз стандарт 140 000 руб. за 15 суток сопоставим с ценой 10…12-суточного круиза «Принцессы Анабеллы» от 137 000 руб.

#### 1.1.5 Объём выручки от реализации

Выручка считается по типам кают - цена круиза, умноженная на число проданных путёвок при загрузке 85 % и 11 рейсах за навигацию. Дополнительные услуги - спа, бар, магазины, экскурсии, гараж, модули солнечной палубы - приняты 15 % круизной выручки по оценке ПЭУ:

Таблица 11

| Статья | Продано путёвок | Цена, руб./чел. | Выручка за навигацию, руб. | Доля, % |
|---|---|---|---|---|
| Люкс | 112 | 275 000 | 30 800 000 | 9,3 |
| Бизнес | 112 | 200 000 | 22 400 000 | 6,8 |
| Стандарт | 823 | 140 000 | 115 220 000 | 34,9 |
| Стандарт М4 | 112 | 126 000 | 14 112 000 | 4,3 |
| Семейная | 673 | 140 000 | 94 220 000 | 28,5 |
| Эконом | 112 | 95 000 | 10 640 000 | 3,2 |
| **Круизы, итого** | **1944** |  | **287 392 000** | 87,0 |
| Дополнительные услуги, 15 % круизной |  |  | 43 108 800 | 13,0 |
| **Выручка за навигацию** |  |  | **330 500 800** | 100 |

В среднем за рейс круизная выручка 26,1 млн руб., при полной загрузке 30,8 млн руб. Судно работает одну навигацию в год, годовая выручка равна выручке за навигацию - 330,5 млн руб. Гараж даже при полной загрузке всех рейсов даёт не более 1,32 млн руб. (4 места × 11 рейсов × 30 000 руб.), основная часть дополнительной выручки - экскурсии, спа и бар. Структура выручки - на рисунке 3.

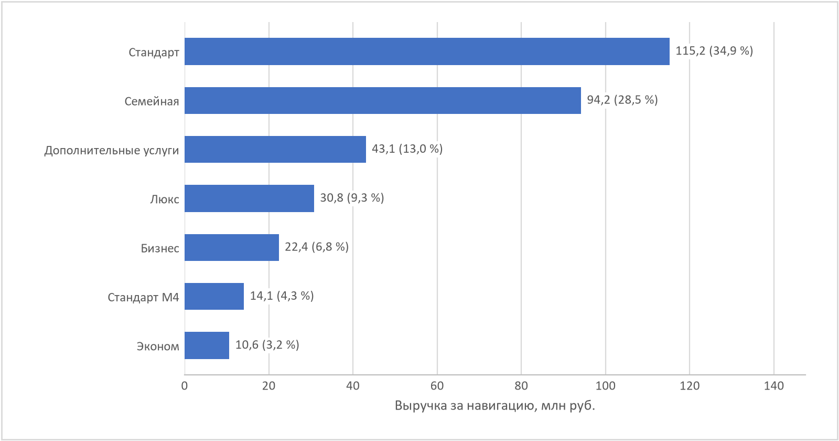
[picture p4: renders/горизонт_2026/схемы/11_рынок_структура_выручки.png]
Структура выручки за навигацию


Рисунок 3 - Структура выручки за навигацию

**Вывод по выручке.** Четырёхместные каюты стандарт и семейные дают 72,9 % круизной выручки - это ядро семейного сегмента. Каюты бизнес и люкс занимают 11,5 % мест и дают 18,5 % круизной выручки. Выручка посчитана по ценам полного круиза при загрузке 85 %.

#### 1.1.6 Конкурентные преимущества

Преимущества посчитаны, а не заявлены:

Таблица 12

| Преимущество | Чем подтверждено |
|---|---|
| Осадка 1,26 м | маршруты с лимитирующими глубинами закрыты для судов с осадкой свыше 2,5 м, расчёт посадки - приложение А.2 |
| Габаритная высота 9,90 м при мосте 13,3 м | рубка стационарная. Над солнечной палубой свободно 5,5 м - 18 слотов под контейнерные модули на фундаментах-твистлоках, 6 тем круизов (листы МР-01…03) |
| КПД движителя 0,68 | против 0,33 у предельного по осадке винта ⌀0,76 м - приложение А.5 |
| Перевозка автомобилей | 4 места класса «Б» до 3,5 т - у речных круизных судов этого нет |
| Доступность | 12 мест группы мобильности М4 при 11 требуемых, в 6 каютах стандарт М4 |
| Возврат сточных вод | два контура, серый и чёрный, экономия 22 м³ пресной воды в сутки |

Для сравнения с судами-аналогами взяты критерии - осадка, класс РКО, выход на Белую до Уфы, доступная среда, энергетическая установка, общественные помещения, год постройки, перевозка автомобилей и число пассажиров на метр длины. Данные аналогов - оценка ПЭУ:

Таблица 13

| Критерий | «Александр Невский» (проект 588) | «Принцесса Анабелла» (проект 463-П) | «Волжский Горизонт» |
|---|---|---|---|
| Осадка | 2,4…2,46 м | 1,98…2,0 м | 1,26 м |
| Класс РКО | «М» | речной | «О 2,0» |
| Белая до Уфы (в межень 1,6…2,2 м) | только в весеннее половодье | только в весеннее половодье | вся навигация, май - октябрь |
| Доступная среда | нет | нет | 12 мест М4, 4 лифта |
| Энергетическая установка | дизель-электрическая, 3 × 6NVD48U | дизельная, 2 × D11643M01P | гибридная - 3 ГДГ на метаноле по 600 кВт, батарея, солнечные модули 24 кВт |
| Общественные помещения | ресторан, бар, музыкальный салон | ресторан, бар, солярий | театр-лаунж с лекторием, спа и фитнес, детский и подростковый клуб с творческой мастерской, панорамный салон-обсерватория, модульная солнечная палуба |
| Постройка | 1957, модернизирован | 1973, модернизация 2006 и 2022 | новое судно, передача заказчику в 2030 |
| Перевозка автомобилей | нет | нет | 4 места класса «Б» |
| Пассажиров на 1 м длины | около 2,5 | нет данных | 1,49 |

Рассмотренные суда-аналоги построены 53 и 69 лет назад, работают на дизельном топливе, не перевозят автомобили и не имеют кают для маломобильных пассажиров. На Белую до Уфы они выходят только в весеннее половодье - в межень глубины 1,6…2,2 м не дают запаса под килём при их осадке. Их сильная сторона - сложившаяся клиентская база и известность операторов, которых у нового судна на старте продаж нет (W4).

#### 1.1.7 Целевая аудитория и сегментация

Маршрут круиза проходит через три реки с заходом в город Уфа по реке Белой. Мелкая осадка 1,26 м открывает Белую и перекаты Камы, куда крупный круизный флот не сможет пройти. Маршрут кольцевой, посадка и высадка пассажиров происходят в одном порту. На судне присутствуют гараж на четыре автомобиля и шесть кают М4, а в дизайне превалирует современный облик вместо ретро-стилизации.

Таблица 14

| Сегмент | Каюты | Мест на рейс | Доля, % | Мест за навигацию | Мотив | Где искать |
|---|---|---|---|---|---|---|
| Семьи с детьми школьного возраста | стандарт, семейная | 160 | 76,9 | 1760 | каникулы на воде без перелёта - Казань, Уфа, Жигули, замок Гарибальди, Чёртово городище. Четыре места в каюте по цене семейного тарифа | школьные каникулы в расписании рейсов, семейные тарифы «дети до 12 бесплатно на верхних местах», туроператоры Поволжья, соцсети регионов |
| Пары 45+ и путешественники старшего возраста | бизнес, люкс | 24 | 11,5 | 264 | неспешное кольцо по трём рекам, музеи и купеческие города, каюты с панорамным окном, ресторан в две смены | круизные агрегаторы, клубы повторных гостей, программы лояльности, печатные каталоги операторов |
| Компании друзей и молодёжь | эконом | 12 | 5,8 | 132 | самый дешёвый билет на 15 дней с Уфой и Казанью. Внутренняя двухместная с виртуальным окном | ранние продажи с глубокой скидкой, коллаборации с вузами, короткие видео из рейса |
| Маломобильные пассажиры с сопровождающими | стандарт М4 | 12 | 5,8 | 132 | каюты М4 с кругом разворота 1,5 м и душем без порога, лифты на всех трап-холлах, путь эвакуации 1,2 м - круиз, который реально доступен | общества инвалидов, социальные туроператоры, программы субсидируемого отдыха |

Рейсов в навигацию 11 (184 суток на Каме и Белой, оборот 16 суток), мест на рейс 208, за навигацию 2288. Сверх кают спрос дают ещё три группы.

- **Автотуристы.** Свой автомобиль в гараже. Выезд в Уфе и Казани на своей машине, обратно - на теплоходе.
- **Корпоративные и групповые заезды.** Театр-лаунж на 68 мест и ресторан в две смены - выездные сессии, юбилеи, фрахт судна целиком в межсезонье.
- **Модульные темы на солнечной палубе.** Контейнерные модули на фундаментах-твистлоках. Деловая, оздоровительная, детская, событийная и президентская темы меняются за смену под спрос сезона - от терм на палубе до президентского люкса.

Маршрут Самара - Казань - Уфа - Самара (Волга, Кама, Белая), 2606 км по фарватеру за 15 дней (рисунки 4 и 5). Путь по фарватеру выгружен в GeoJSON для мобильного приложения. Ёмкость рынка, цены и конкуренты - 1.1.2…1.1.6.

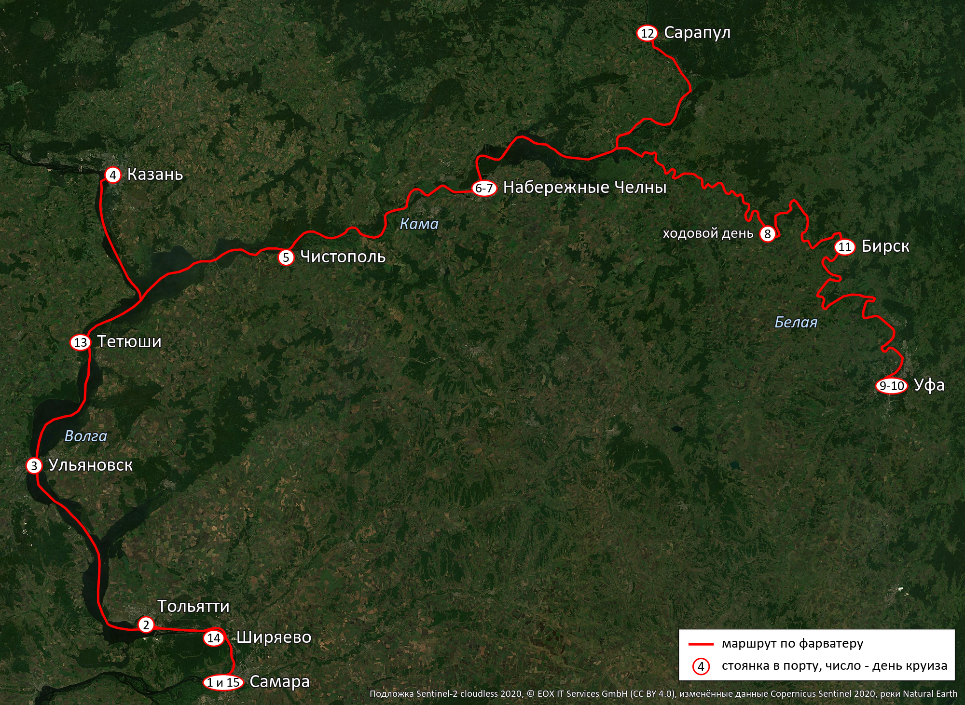
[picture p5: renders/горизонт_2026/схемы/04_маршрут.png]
Маршрут на спутниковом снимке


Рисунок 4 - Маршрут на спутниковом снимке

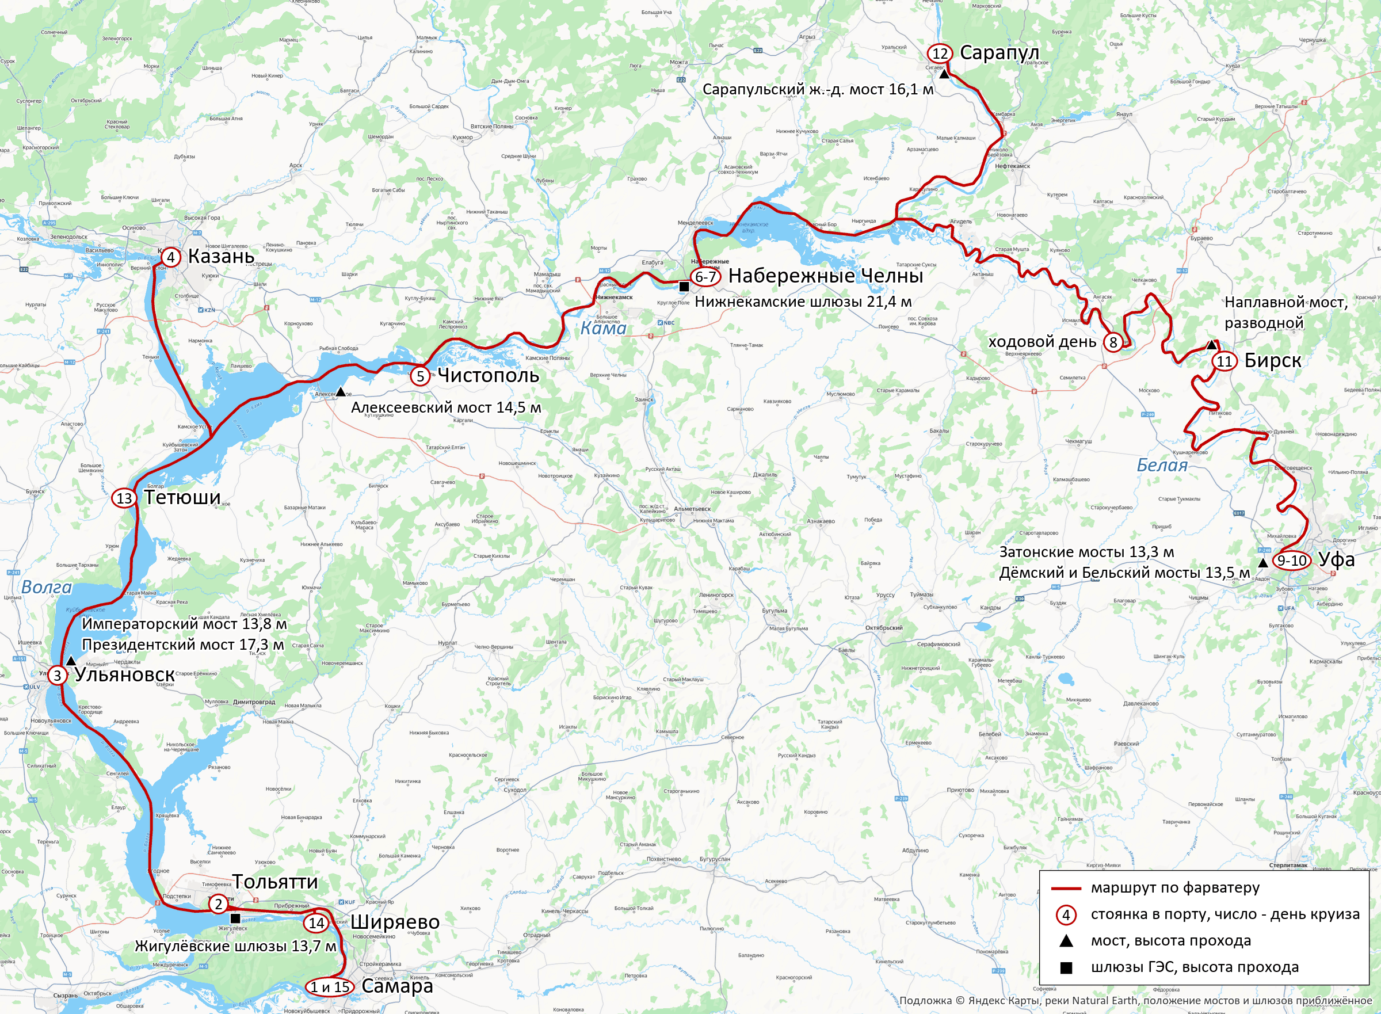
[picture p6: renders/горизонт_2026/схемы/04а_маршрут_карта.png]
Маршрут с мостами и шлюзами


Рисунок 5 - Маршрут с мостами и шлюзами

#### 1.1.8 Маркетинговая стратегия

Стратегия построена по модели 4P - продукт, цена, сбыт, продвижение:

Таблица 15

| Элемент | Решения |
|---|---|
| Продукт | 1) Колёсное круизное судно мелкой осадки 1,26 м - Белая до Уфы и перекаты Камы, куда суда с осадкой около 2 м и больше в межень не заходят. 2) Модель «круиз-конструктор» - каюта, питание и общественные помещения в цене путёвки, экскурсии, гараж и спа отдельно, выбор порта окончания круиза. 3) Градация сервиса по 6 типам кают в четырёх категориях КЗ - эконом, стандарт, бизнес, люкс. 4) Перевозка 4 автомобилей класса «Б», 12 мест М4, модульная солнечная палуба с 6 темами, ужин с капитаном. 5) Гибридная энергетика - метанол, батарея, солнечные модули, ход на батарее в черте городов без выхлопа. Современный облик вместо ретро-стилизации. |
| Цена | 1) Каюты бизнес и люкс - ниже цен премиальных аналогов при сопоставимом уровне кают, бизнес 200 000 руб. против 214 000 руб. у «Игоря Стравинского». 2) Каюты эконом и стандарт - на уровне рынка, 6333 и 9333 руб. в сутки полного круиза. 3) Средневзвешенная цена путёвки 147 846 руб. за 15 суток, 9856 руб. в сутки. 4) Гибкое ценообразование - сезон, загрузка рейса, раннее бронирование со скидкой 15 %. 5) Дополнительная выручка - экскурсии, гараж, спа, модули солнечной палубы по отдельному прайсу. |
| Сбыт | 1) Прямые продажи - собственный сайт с онлайн-конструктором круиза, отдел продаж. 2) Партнёрская сеть - туроператоры и турагентства Поволжья, комиссия 10…12 %. 3) Корпоративное направление - фрахт, корпоративные заезды, MICE (деловой туризм - встречи, поощрительные поездки, конференции, выставки). 4) Раннее бронирование - продажи за 6 месяцев до рейса со скидкой 15 %. 5) Групповые продажи - тарифы для компаний друзей, семейных групп, обществ инвалидов. |
| Продвижение | 1) Интернет - SEO (поисковая оптимизация), контекстная реклама, SMM (продвижение в социальных сетях) во ВКонтакте и Telegram, блогеры-путешественники и автоблогеры. 2) PR (связи с общественностью) - выставки MITT и «Интурмаркет», пресс-туры для журналистов и блогеров, съёмка колёсного хода с дрона, видео смены модульных тем. 3) Партнёрства - автоклубы, общества и фонды инвалидов, коворкинги и IT-сообщества, туроператоры Поволжья, вузы. 4) Акция «Собери свой круиз» - скидка 10 % при покупке трёх и более экскурсий, программа лояльности для повторных гостей. |

**Вывод по маркетинговой стратегии.** Стратегия опирается на продукт, отличный от рассмотренных аналогов. Это колёсное судно мелкой осадки с гаражом, каютами М4 и модульной солнечной палубой, которое продаётся по модели «круиз-конструктор». Цены массовых кают на уровне рынка, премиальных - ниже аналогов. Сбыт идёт через прямые продажи, партнёрскую сеть и корпоративных клиентов, продвижение - через интернет, выставки и сообщества целевых сегментов. На этом строится плановая загрузка 85 % во всех четырёх сегментах.

## 2 Дизайн-проект

### 2.1 Графическое изображение проекта

**Палитра.**

Таблица 16

| Назначение | Цвет |
|---|---|
| графит | `#2E3338` |
| графит_тёмный | `#20242A` |
| графит_светлый | `#3C444C` |
| графит_серебро | `#A9AFB5` |
| чёрный | `#15181C` |
| красный | `#C8102E` |
| красный_тёмный | `#9E0C24` |
| белый | `#EDEFF1` |
| серый_тёплый | `#C9CDD2` |
| стекло | `#1B2733` |
| стекло_тон | `#252f38` |
| дерево | `#B08658` |
| дерево_тёмное | `#6E4F30` |
| сталь | `#8A9099` |

**Разделение по высоте.** Тёмный низ зрительно опускает судно на воду, светлый верх делает его лёгким, на стыке - фирменная красная полоса.

Таблица 17

| Пояс | Цвет | От | До |
|---|---|---|---|
| подводная часть | графит_тёмный | основная | 1,20 м |
| борт корпуса | графит | 1,20 м | 3,00 м |
| акцентная полоса | красный | 1,10 м | 1,45 м |
| надстройка | белый | 3,00 м | верх |

У красной полосы светлая отбивка 40 мм, так как контраст красного к графиту 2.17 при пороге читаемости 3,0 - оба цвета тёмные, и с берега полоса сливалась бы с бортом. Яркость красного не повышается, чтобы цвет оставался фирменным. Светлая отбивка даёт контраст 11.06.

Радиус скругления надстройки в плане 1.20 м, передней кромки 2.40 м, фаска видимых рёбер 0.15 м, завал бортов 6.0°, непрерывная лента остекления высотой 1.85 м на 0.45 м от палубы.

Облик в 2D (рисунки 6…8), виды трёхмерной модели (рисунки 9…16, солнечная палуба - с модулями темы «президентская»), взрыв-модель (рисунок 17), судно у причала порта приписки, смена модуля краном и сход на берег (рисунки 18…20). Общее расположение - чертежи ОР-01…08.

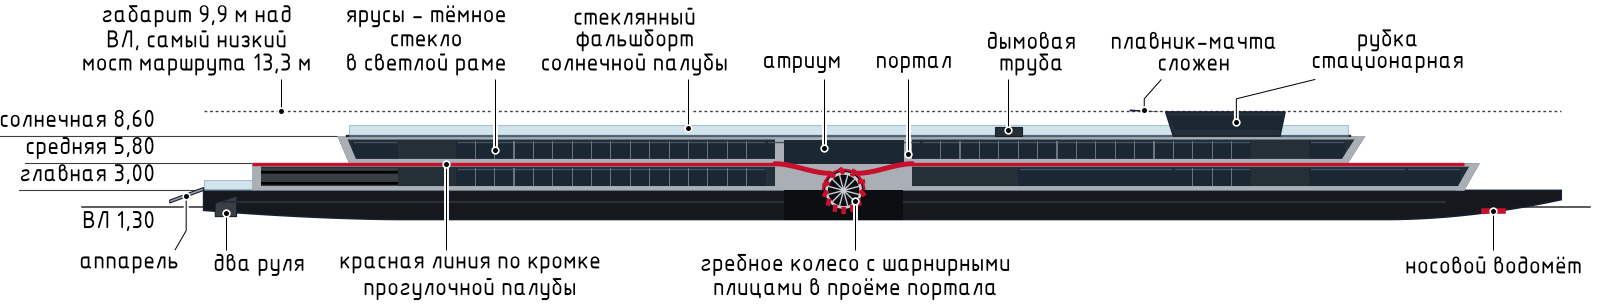
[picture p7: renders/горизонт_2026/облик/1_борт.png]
Облик судна, вид сбоку


Рисунок 6 - Облик судна, вид сбоку

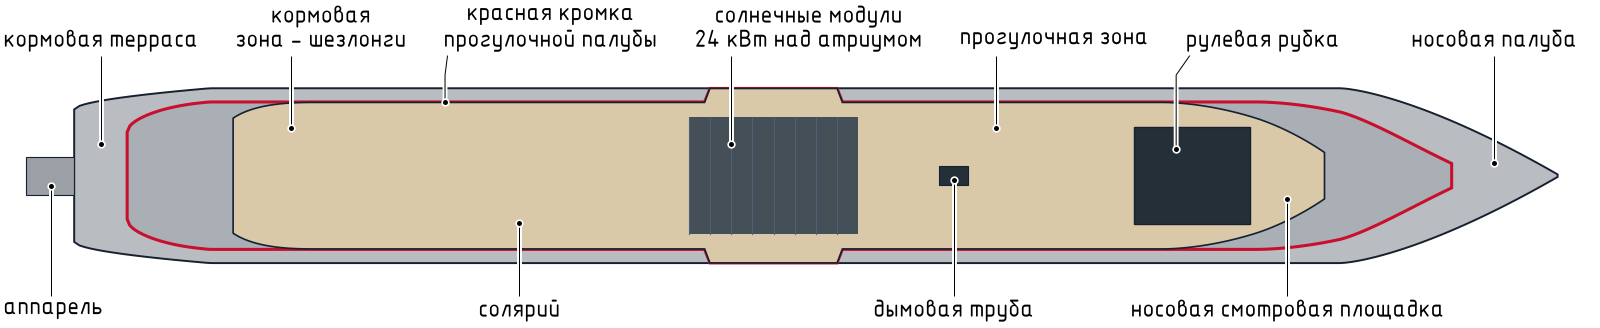
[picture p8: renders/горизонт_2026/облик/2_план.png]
Облик судна, вид сверху


Рисунок 7 - Облик судна, вид сверху

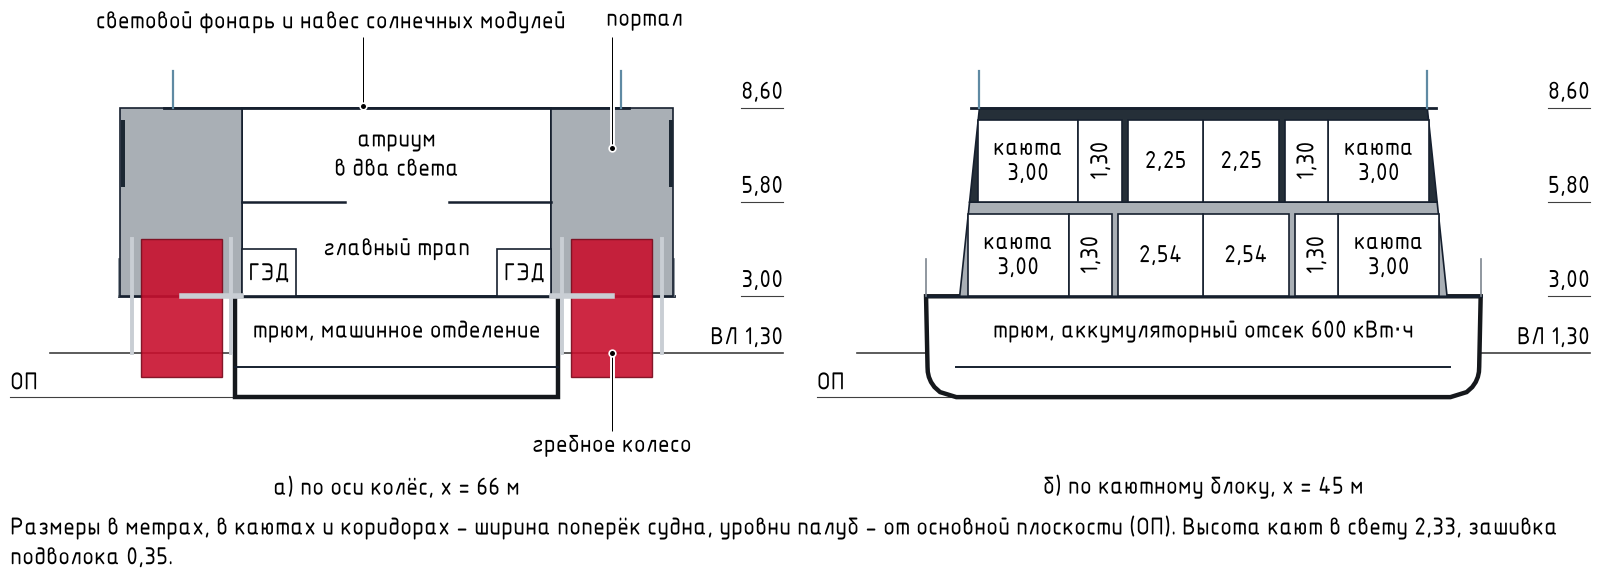
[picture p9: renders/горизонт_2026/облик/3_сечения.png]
Облик судна, поперечные сечения


Рисунок 8 - Облик судна, поперечные сечения

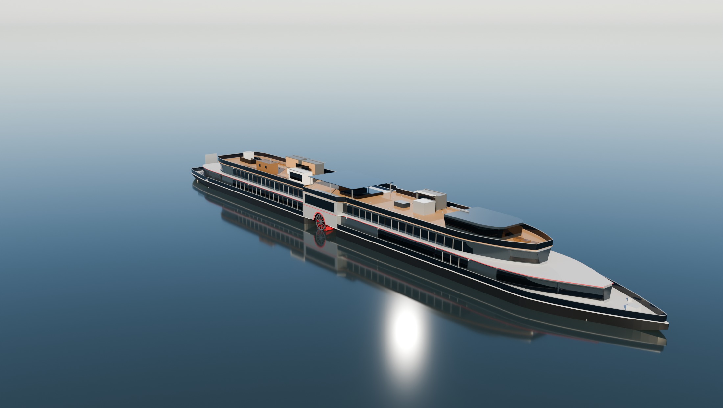
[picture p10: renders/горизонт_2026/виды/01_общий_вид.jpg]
Общий вид судна


Рисунок 9 - Общий вид судна

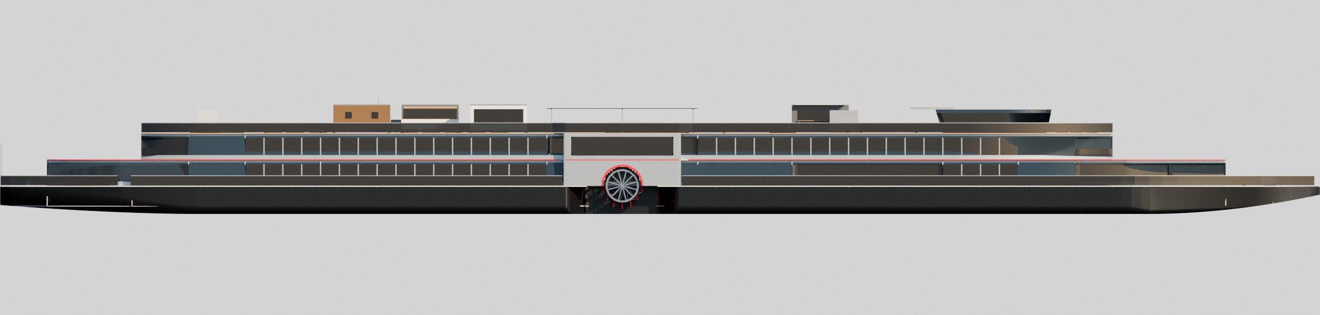
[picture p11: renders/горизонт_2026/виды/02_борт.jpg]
Судно, вид с борта


Рисунок 10 - Судно, вид с борта

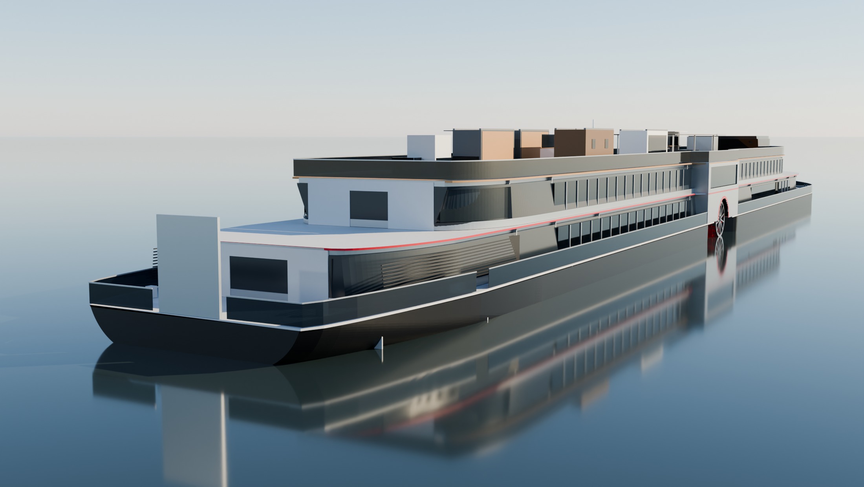
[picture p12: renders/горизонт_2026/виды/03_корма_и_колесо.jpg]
Корма и гребное колесо


Рисунок 11 - Корма и гребное колесо

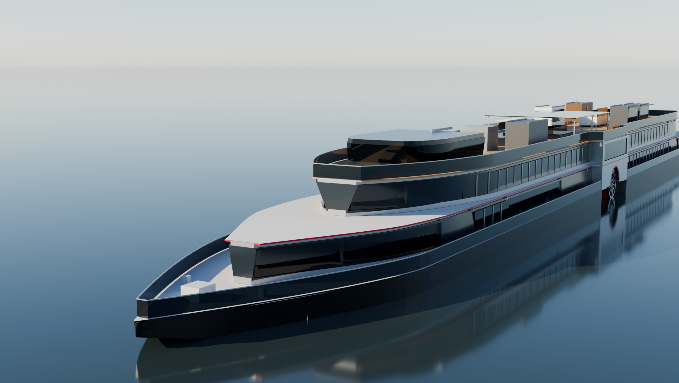
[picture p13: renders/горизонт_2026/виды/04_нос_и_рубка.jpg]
Нос и рулевая рубка


Рисунок 12 - Нос и рулевая рубка

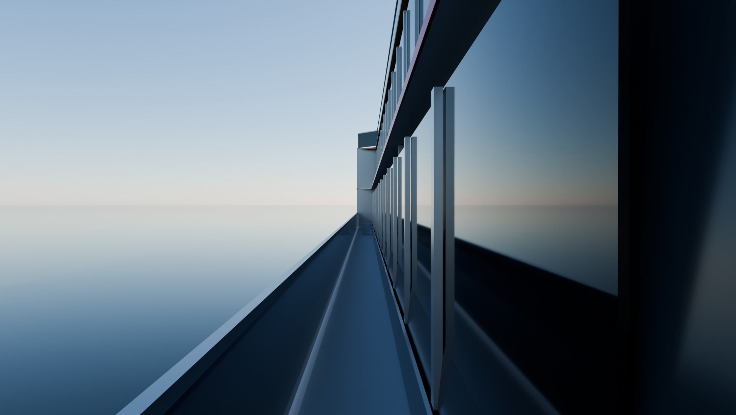
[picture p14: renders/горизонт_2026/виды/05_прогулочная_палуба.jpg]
Прогулочная палуба


Рисунок 13 - Прогулочная палуба

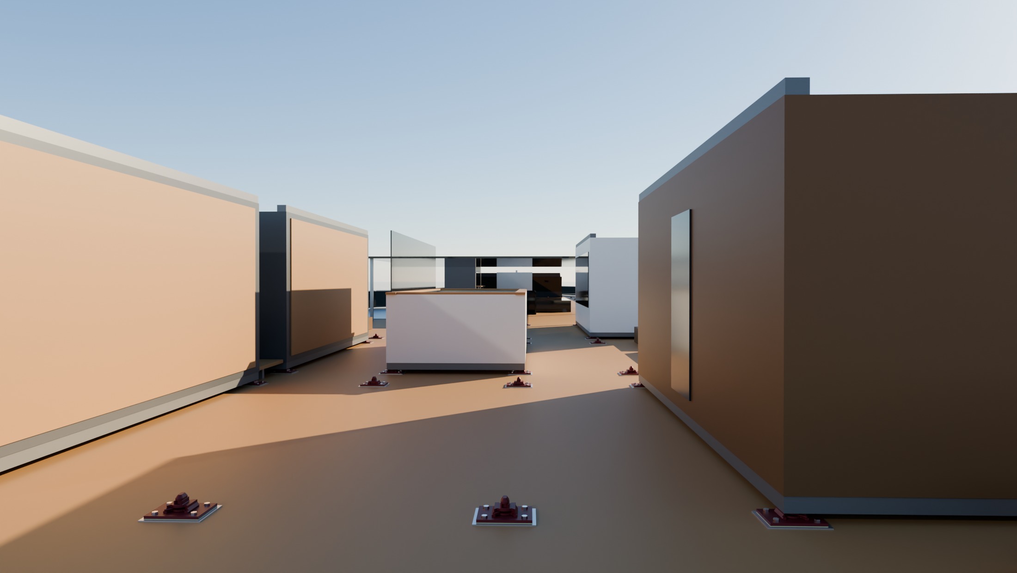
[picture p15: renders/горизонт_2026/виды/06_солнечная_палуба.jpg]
Солнечная палуба с модулями темы «президентская»


Рисунок 14 - Солнечная палуба с модулями темы «президентская»

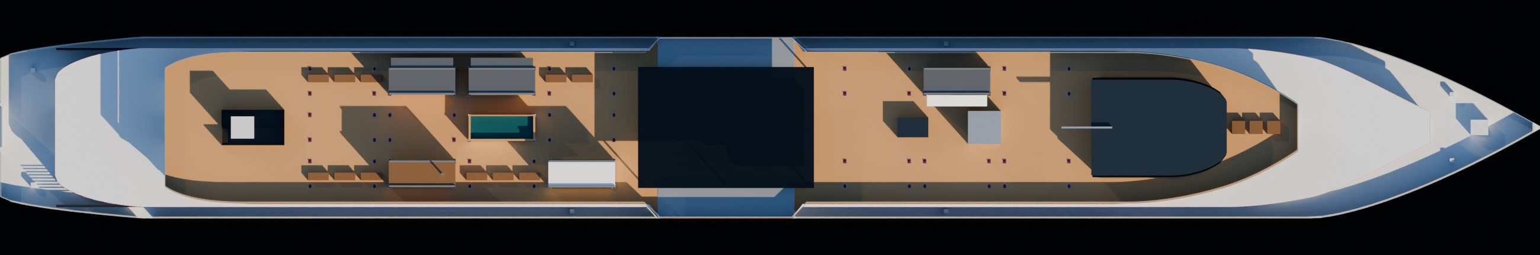
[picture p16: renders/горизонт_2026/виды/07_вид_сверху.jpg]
Судно, вид сверху


Рисунок 15 - Судно, вид сверху

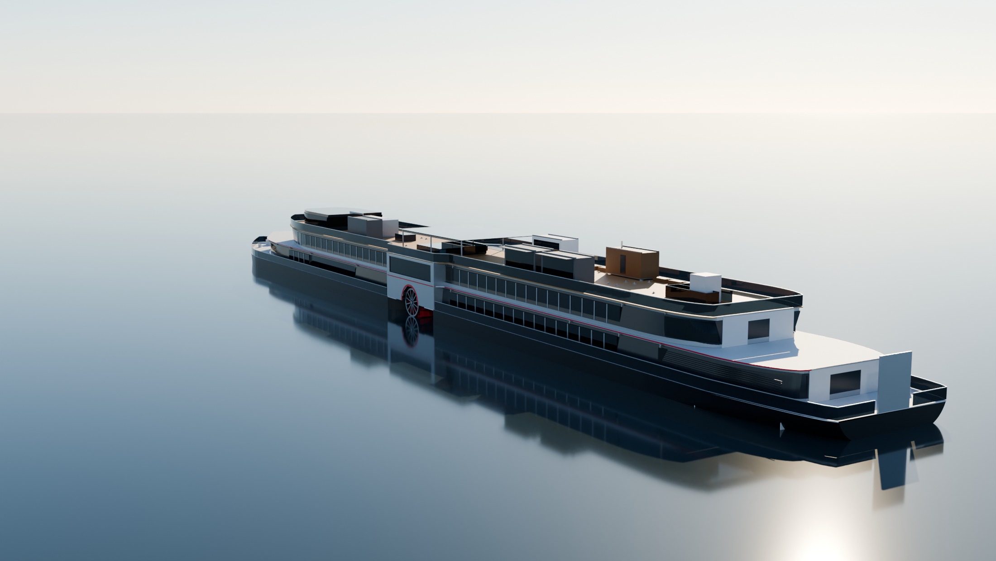
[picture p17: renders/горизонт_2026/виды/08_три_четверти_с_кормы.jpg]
Судно, вид с кормы


Рисунок 16 - Судно, вид с кормы

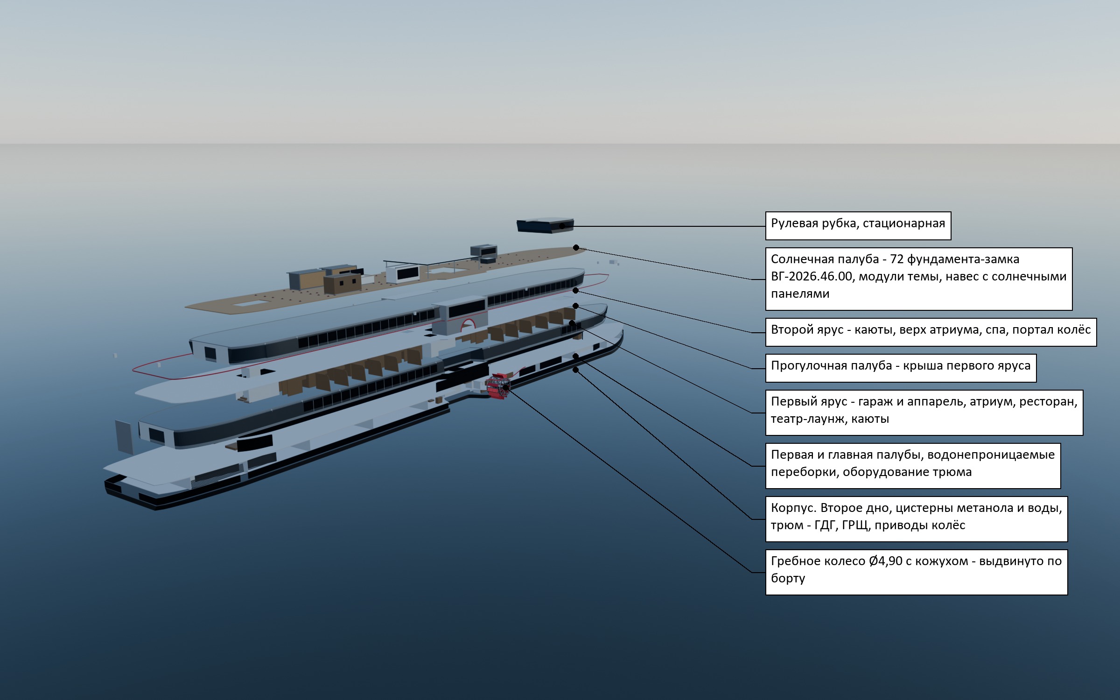
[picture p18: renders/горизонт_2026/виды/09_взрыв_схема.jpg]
Компоновочная схема (взрыв-модель)


Рисунок 17 - Компоновочная схема (взрыв-модель)

Судно у причала порта приписки

Рисунок 18 - Судно у причала порта приписки

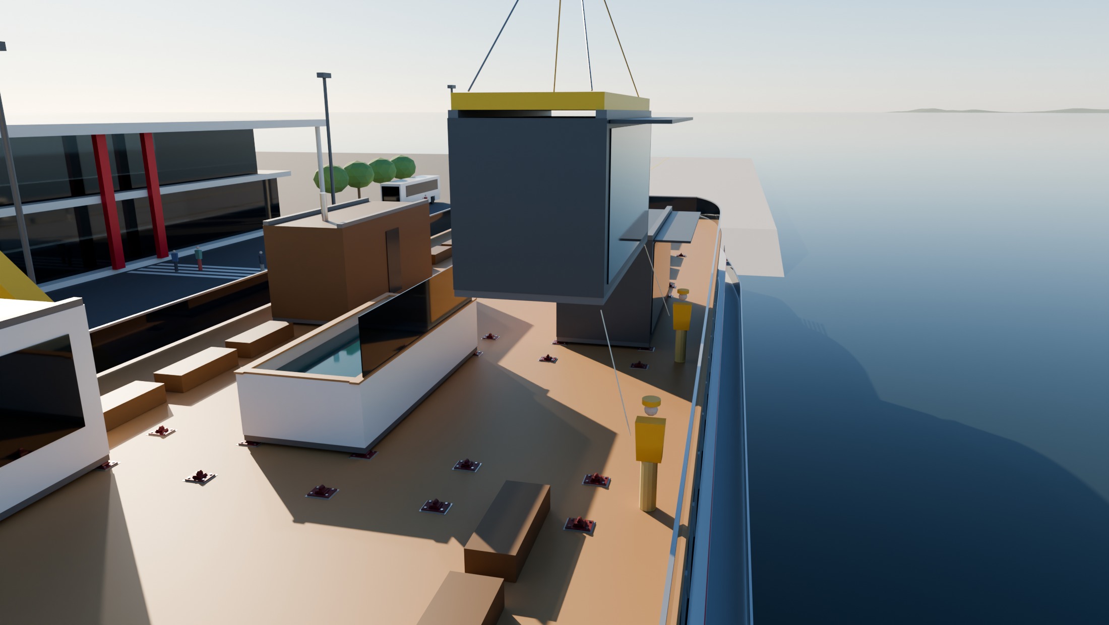
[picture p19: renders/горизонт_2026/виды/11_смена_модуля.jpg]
Смена модуля краном причала


Рисунок 19 - Смена модуля краном причала

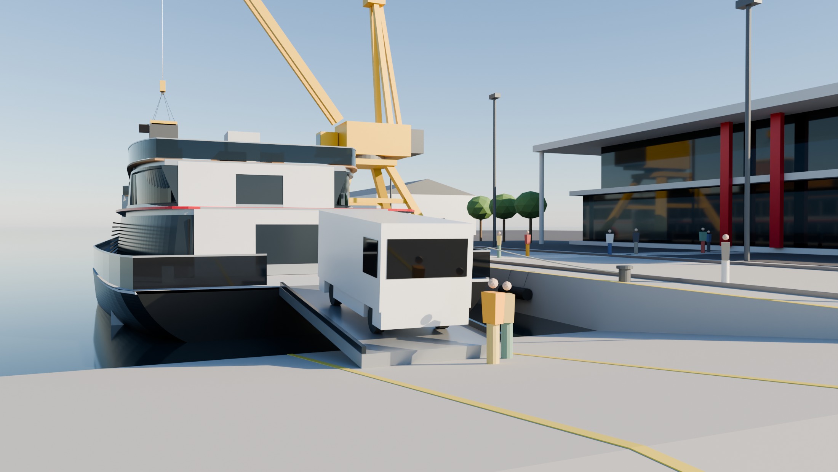
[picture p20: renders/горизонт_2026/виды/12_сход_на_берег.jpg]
Сход пассажиров по трапу и автомобилей по аппарели


Рисунок 20 - Сход пассажиров по трапу и автомобилей по аппарели

### 2.2 Общественные помещения, развлечения и сервисы

Расстановка помещений, мебели и посадочных мест - на планах палуб (рисунки 21…23) и чертежах ОР-01…03.

Культурно-развлекательные сервисы:

- Театр-лаунж (концерты, кинопоказы, лекторий, вечером клуб).
- Спа-комплекс с банным блоком и фитнес-залом.
- Детский и подростковый клуб.
- Творческая мастерская народных промыслов Поволжья.
- Панорамный салон-обсерватория с лекторием «Города Кругосветки».

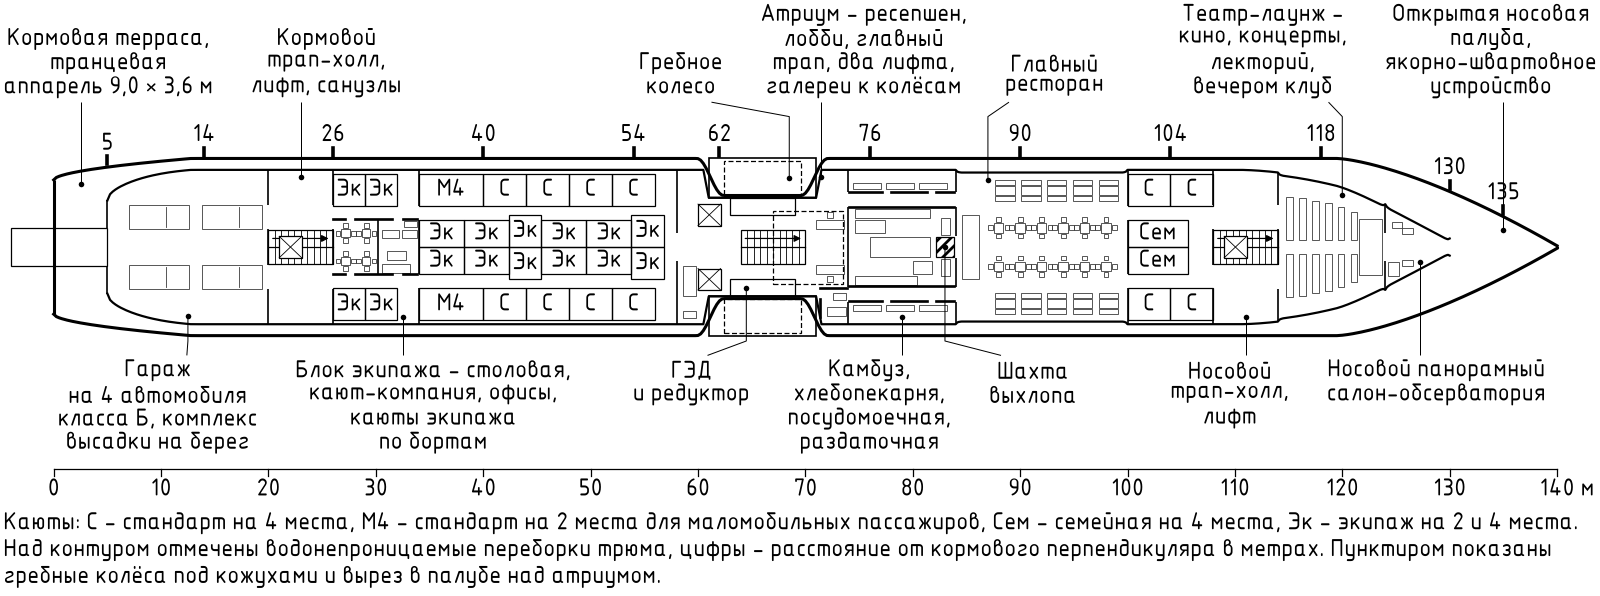
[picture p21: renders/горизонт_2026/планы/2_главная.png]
План главной палубы


Рисунок 21 - План главной палубы

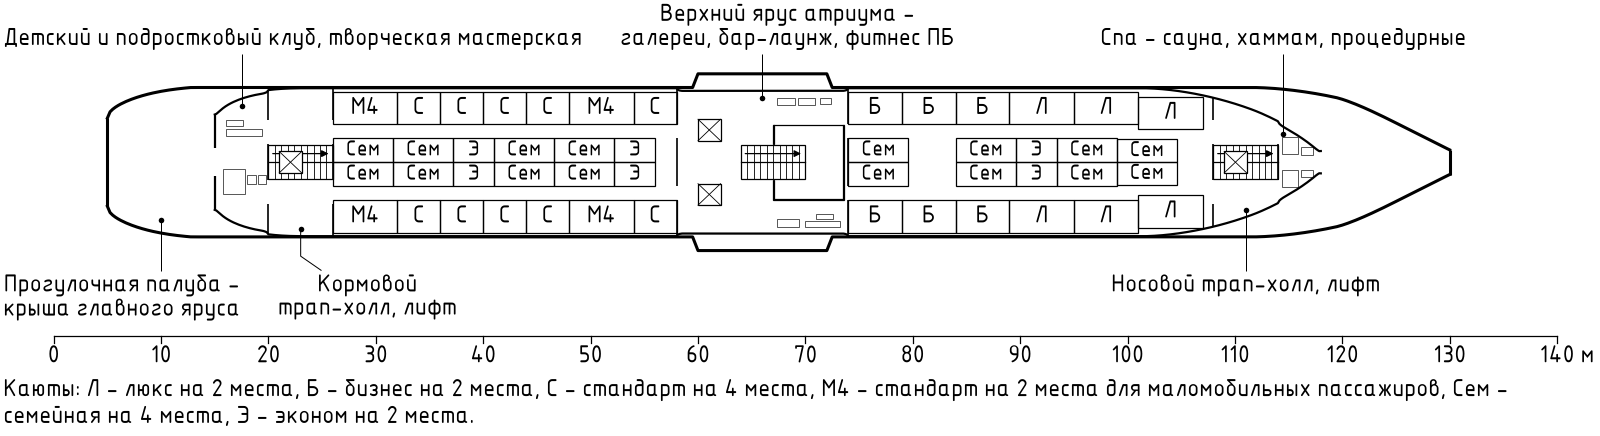
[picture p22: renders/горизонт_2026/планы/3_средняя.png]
План средней палубы


Рисунок 22 - План средней палубы

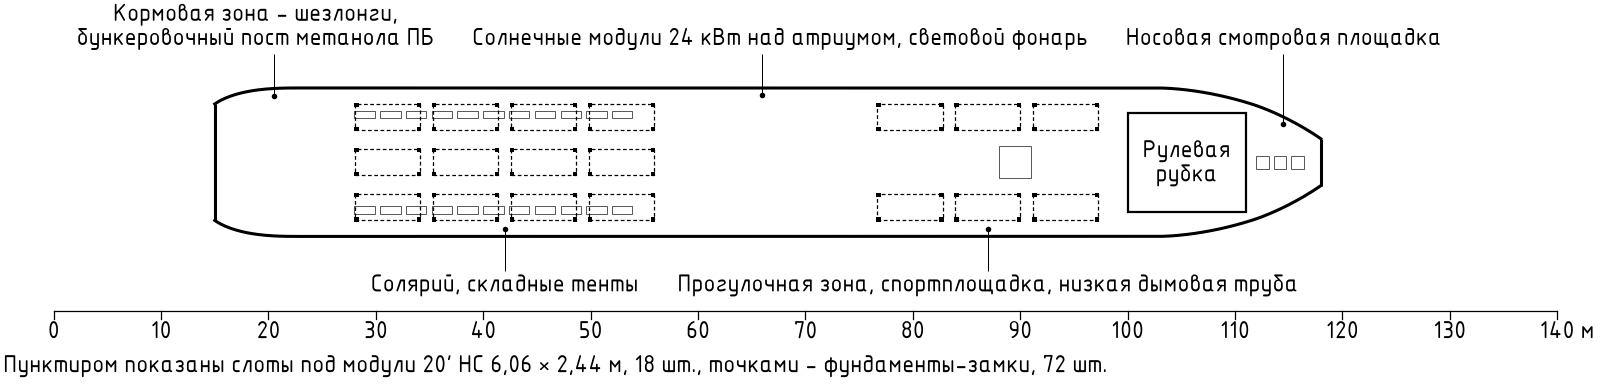
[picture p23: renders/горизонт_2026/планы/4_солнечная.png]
План солнечной палубы


Рисунок 23 - План солнечной палубы

Таблица 18

| Помещение | Палуба | x, м | м² | Мест | Для кого и почему здесь |
|---|---|---|---|---|---|
| Атриум - ресепшен, лобби, главный трап, два лифта, галереи к колёсам | главная | 58…74 | 178 |  | всем. Ресепшен, лобби, галереи к гребным колёсам - «машина, которую видно» (витражи в щеках кожухов), центр судна на оси колёс |
| Главный ресторан | главная | 84…100 | 222 | 108 мест в смену | все 208 пассажиров в две смены. Рядом камбуз, под ним провизионные кладовые с лифтом - короткая раздача |
| Театр-лаунж - кино, концерты, лекторий, вечером клуб | главная | 114…124 | 112 | 68 сидячих + бар | вечерняя программа для всех. Днём лекторий и кино для семей и пар 45+, вечером клуб для компаний, 68 мест - корпоративные и групповые заезды |
| Носовой панорамный салон-обсерватория | главная | 124…130 | 26 |  | пары 45+ и все, кто хочет вид вперёд по курсу - бар, диваны, лекторий «Города Кругосветки» |
| Детский и подростковый клуб, творческая мастерская | средняя | 15…20 | 58 |  | семьи с детьми - три четверти мест на судне. Творческая мастерская промыслов Поволжья. Выход на кормовую террасу-крышу, в стороне от кают |
| Верхний ярус атриума - галереи, бар-лаунж, фитнес ПБ | средняя | 58…74 | 213 |  | бар-лаунж и фитнес на галереях над колёсами - дневное место встречи. Без выделенной площади, на проёме атриума |
| Спа - сауна, хаммам, процедурные | средняя | 114…118 | 19 |  | сауна, хаммам, процедурные - пары 45+ и оздоровительные рейсы, в носу, вдали от кают и машин |

Бары - бар-лаунж на галерее атриума (средняя), бар носового салона (главная), бар солнечной палубы. Медпункт и изолятор - в атриуме за кожухом ЛБ. Все общественные помещения выходят на три трап-холла с лифтами, путь эвакуации шириной не менее 1,2 м.

**Солнечная палуба** - солярий и шезлонги, бар, спортплощадка, смотровая. Отдельно - модульные темы на фундаментах-твистлоках (листы МР-01…03, документ «Модульное решение солнечной палубы») - тема меняется за смену краном причала, всё в пределах 85 т и расчётной осадки.

Таблица 19

| Тема | Что это | Модули | т | кВт |
|---|---|---|---|---|
| деловая | деловые круизы - восемь кабинетов и переговорных по бортам, бар | офис × 8, бар × 1 | 33,0 | 56 |
| оздоровительная | термы на палубе - четыре сауны с купелями, два мелких бассейна в ДП, два кабинета процедур, бар | спа × 4, бассейн × 2, офис × 2, бар × 1 | 60,4 | 92 |
| детская | детские круизы - шесть игровых модулей, клубный блок для анимации, бар | детский × 6, клуб × 3, бар × 1 | 34,2 | 35 |
| событийная | диско, кино, театр, свадьбы - два клубных блока по три секции, гримёрная, бар | клуб × 6, офис × 1, бар × 1 | 31,8 | 44 |
| президентская | остров на плаву - люкс из двух секций с террасой, сауна, мелкий бассейн, кабинет, бар | спа × 1, люкс × 2, бассейн × 1, офис × 1, бар × 1 | 36,4 | 45 |

### 2.3 Интерьеры кают и отделка по классам

Шесть типов кают на 208 пассажиров (стандарт 28, эконом 24, бизнес 6, люкс 6), из них шесть кают М4 на 12 мест. Планировки с проверкой эргономики по СанПиН 2.5.2-703-98 (49 проверок) - на рисунке 24, интерьеры по три ракурса на тип - на рисунке 25. Отделка задана по классам кают - чем выше класс, тем дороже материалы, и рендеры собраны из тех же цветов.

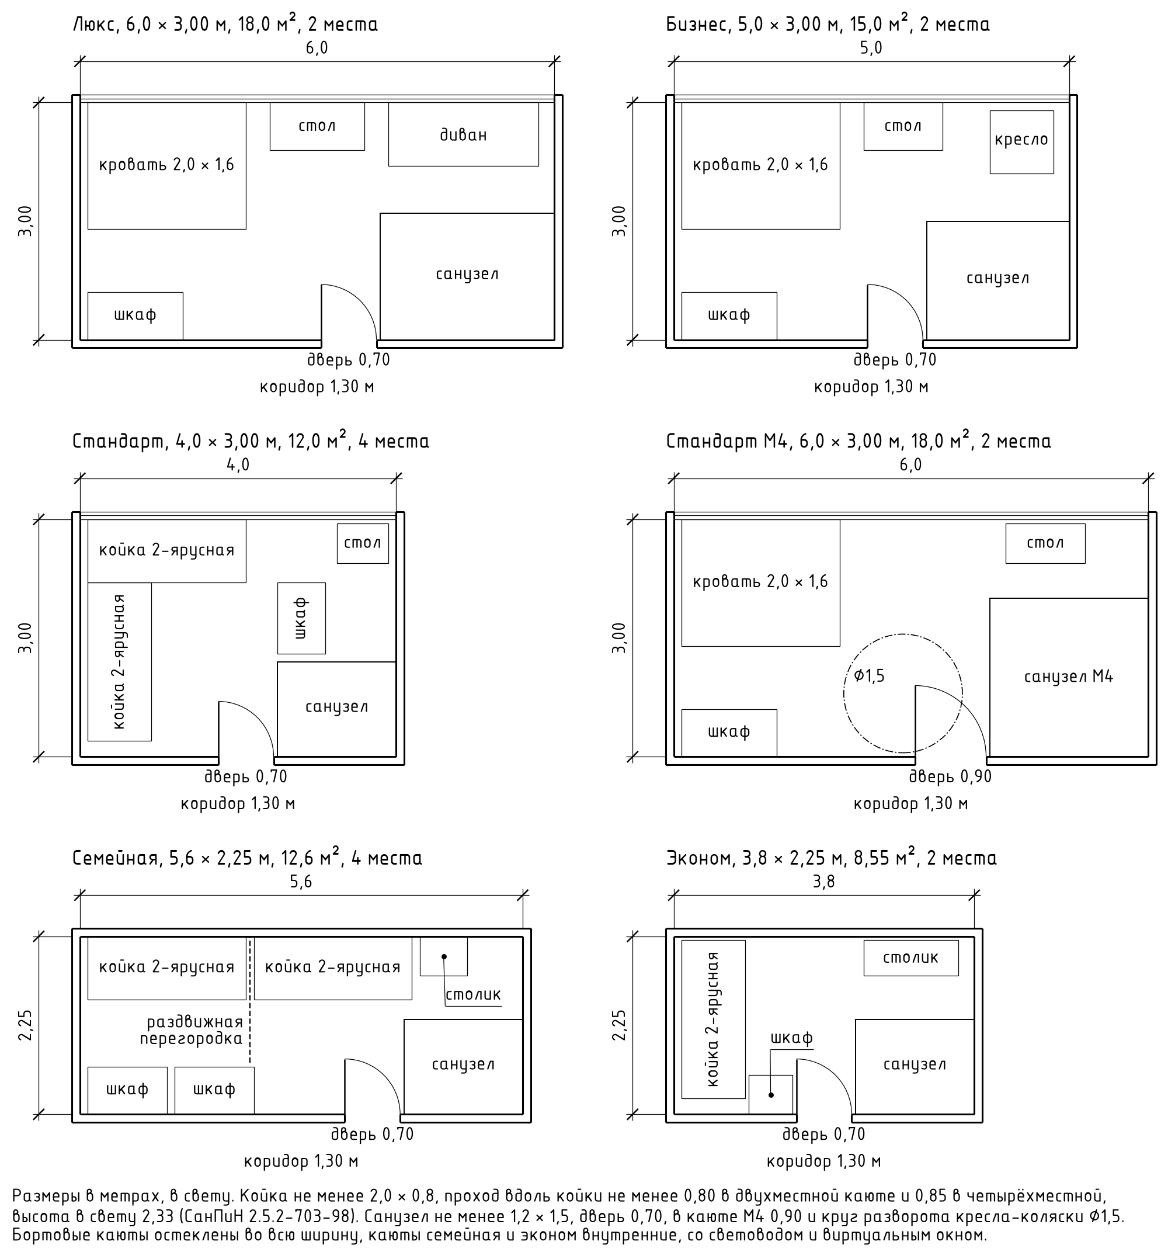
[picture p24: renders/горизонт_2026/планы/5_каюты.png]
Планировки кают шести типов


Рисунок 24 - Планировки кают шести типов

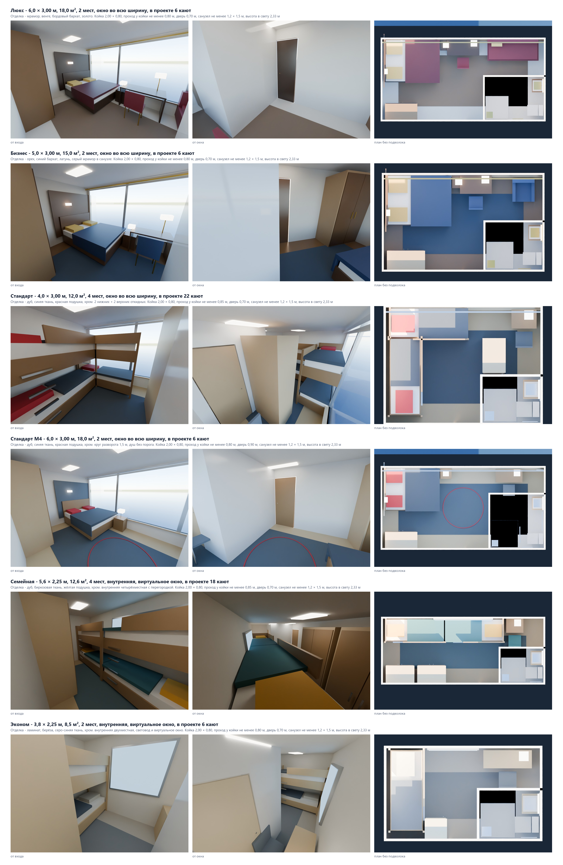
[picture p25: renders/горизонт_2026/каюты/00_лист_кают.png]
Интерьеры кают шести типов


Рисунок 25 - Интерьеры кают шести типов

Таблица 20

| Класс | Отделка |
|---|---|
| эконом | ламинат, берёза, серо-синяя ткань, хром |
| стандарт | дуб, синяя ткань, красная подушка, хром |
| семейная | дуб, бирюзовая ткань, жёлтая подушка, хром |
| бизнес | орех, синий бархат, латунь, серый мрамор в санузле |
| люкс | мрамор, венге, бордовый бархат, золото |
| стандарт М4 | дуб, синяя ткань, красная подушка, хром |

### 2.4 Модельный ряд

Три версии на одном корпусе (рисунок 26) - корпус, набор, энергетическая установка, колёса и все расчёты общие, меняется только насыщение жилых палуб по сетке шпаций 550 мм. Построена и посчитана версия «Классик».

Модельный ряд, три версии на одном корпусе

Рисунок 26 - Модельный ряд, три версии на одном корпусе

Таблица 21

| Версия | Кают | Мест | Экипаж | На борту | Площадь кают, м² | Разница с «Классиком», м² | м² кают на место | Мест М4, есть и нужно | Не менее 200 мест |
|---|---|---|---|---|---|---|---|---|---|
| ВГ-140-Э Эконом | 86 | 260 | 48 | 308 | 946,2 | +98,1 | 3,64 | 12 и 13 | да |
| ВГ-140-К Классик | 64 | 208 | 48 | 256 | 848,1 | 0 | 4,08 | 12 и 11 | да |
| ВГ-140-П Премиум | 42 | 100 | 48 | 148 | 670,8 | -177,3 | 6,71 | 12 и 5 | нет |

- **Эконом.** Максимальная вместимость - короткие маршруты выходного дня и корпоративные рейсы. Тот же фронт бортов - люксы 6,0 м и бизнес 5,0 м заменены стандартами 4,0 м с откидными верхними койками. Внутренние семейные - двухместными эконом.
- **Классик.** Базовая версия, построена в модели - баланс цены и комфорта. Все чертежи, расчёты и рендеры проекта выполнены для этой версии.
- **Премиум.** Минимум кают, максимум площади на пассажира и общественных пространств. Бортовые ряды - только люкс и бизнес по 2 места. Внутренние эконом объединены в семейные и лаунжи палуб, спа расширяется на освободившийся ряд.

«Эконом» на 260 мест требует 13 мест М4 при 12 имеющихся, в этой версии добавляется каюта М4.
«Премиум» на 100 мест не отвечает КЗ по вместимости и предлагается как версия для другого сегмента.

### 2.5 Судовые системы

Таблица 22

| Требование КЗ | Решение | Где обосновано |
|---|---|---|
| Очистка и повторное использование сточных вод | два контура. Чёрные - вакуумные туалеты, буфер 4 м3 -> мембранный биореактор -> УФ -> танк очищенной 8 м3 -> обратно на смыв, серые - буфер 16 м3 -> биоблок -> УФ -> танк очищенной 24 м3 -> мытьё палуб, обмывка борта, балласт, экономия пресной воды 22 м³ в сутки | схема очистки. Станции СОСВ-Ч и СОСВ-С в трюме x 5…14, лист ОР-04 |
| Гибридная электроустановка | метаноло-электрическая гибридная - 3 ГДГ по 600 кВт, батарея 600 кВт·ч, солнечные модули 24 кВт, береговое питание, на ходу 1280 кВт из 1800, на стоянке 698 кВт | электробаланс, лист РТ-07 |
| Топливо СПГ, метанол или водород | метанол (двухтопливные ГДГ с дизельным запальным), 215 м³ метанола на 15 суток в цистернах второго дна с коффердамами, запальное дизельное 12 м³. Бункеровка автоцистерной на любом причале | цистерны второго дна, лист ОР-04 |
| Раннее предупреждение качки | две U-образные успокоительные цистерны УЦ-1, УЦ-2 (x 46…58 и 84…96), вода 84 т (3,5 % водоизмещения), крен на резонансе с 19,8° до 10,9°. Период цистерны настроен на период качки судна 3,35 с сечением канала. Датчики - MRU, гирокомпас, волномерный радар, метеостанция, акселерометры | расчёт качки, приложение А.6 |
| Автономное управление и исключение столкновений | Судно с автоматическим управлением, экипаж на борту (вторая степень по градации ИМО MASS), 9 датчиков (два радара, АИС, лидар, камеры, тепловизоры, ГНСС RTK, эхолот, микрофоны). Потребная дальность обнаружения 601 м при реакции 26 с, выбег до остановки 174 м за 71 с. Отказоустойчивость - 5 сценариев деградации | расчёт дальности обнаружения и выбега |
| Комплекс высадки на необорудованный берег | в кормовом блоке главной палубы x 5…20 вместе с гаражом - телескопический трап по левому борту, пост дронов, швартовное устройство, транцевая аппарель 9,0 × 3,6 м | план главной палубы, лист ОР-01 |
| Модульные решения по каютам и сервисам | 18 слотов под контейнерные модули на солнечной палубе, шесть тем круизов, модельный ряд из трёх версий по каютам | разделы 2,2 и 2,4, листы МР-01…03 |

## 3 Конструкторская документация

**Узел - ВГ-2026.46.00 «Фундамент-замок модуля (твистлок «ласточкин хвост»)»**. Он держит модульные номера «трансформера» на солнечной палубе, на судне 72 фундамента под угловыми фитингами контейнеров. Узел собирается из четырёх основных деталей и шайбы-подковы и выпускается как самостоятельное производство в арендованном цехе рядом с верфью. Полный разбор - в записке к узлу ВГ-2026.46.00.

- **Корпус, поз. 1** - отливка из стали 20ГСЛ 175 × 160 × 76 мм, 7,55 кг. Снизу две опорные полосы «ласточкина хвоста», ими корпус приварен к платику. Сверху плечо под фитинг и центратор 60 × 116 мм, который входит в отверстие фитинга ISO 1161 и принимает сдвиг. Сквозное отверстие Ø30 под вал запора, внутри полость рукоятки с поворотом на 74°.
- **Стержень, поз. 2** - рукоятка Ø14 из круга 40Х на резьбе в валу, поворачивает запор от выреза до выреза корпуса.
- **Элемент запирающий (конус-голова), поз. 3** - поковка 40Х, голова 104 × 54 мм, вал Ø30.
- **Платик, поз. 4** - лист 09Г2С 375 × 280 × 20 мм, четыре овала 26 × 45 под болты М24 А4-80, окно под шайбу.
- **Шайба разрезная (подкова), поз. 5** - лист 09Г2С, Ø50 × 12 мм в проточке вала под корпусом. Отрыв идёт с вала через шайбу на низ корпуса вокруг отверстия, стержень только поворачивает запор.

Платик ставится на подкладной лист АМг5, приваренный к настилу над подпалубной балкой, через изолирующую прокладку, болты в изолирующих втулках. Высота опоры над настилом 77 мм, масса узла 27,1 кг, с подкладным листом 30,1 кг.

### 3.1 Чертёж узла

Сборочный чертёж ВГ-2026.46.00 СБ (рисунок 27), чертежи деталей ВГ-2026.46.01…05 и спецификация по ГОСТ 2.106 на двух листах. Состав узла:

Узел ВГ-2026.46.00, сборочный чертёж

Рисунок 27 - Узел ВГ-2026.46.00, сборочный чертёж

Таблица 23

| Поз. | Обозначение | Наименование | Кол. | Материал | Масса, кг |
|---|---|---|---|---|---|
| 1 | ВГ-2026.46.01 | Корпус (отливка) | 1 | Сталь 20ГСЛ ГОСТ 977-88 | 7,55 |
| 2 | ВГ-2026.46.02 | Стержень Ø14 × 127 | 1 | Круг 40Х ГОСТ 2590-2006 | 0,15 |
| 3 | ВГ-2026.46.03 | Элемент запирающий (конус-голова) | 1 | Сталь 40Х, поковка КП 590 | 1,45 |
| 4 | ВГ-2026.46.04 | Платик 375 × 280 × 20 | 1 | Лист 09Г2С ГОСТ 19281-2014 | 14,93 |
| 5 | ВГ-2026.46.05 | Шайба разрезная (подкова) Ø50/22,5 × 12 | 1 | Лист 09Г2С ГОСТ 19281-2014 | 0,12 |
| 6 | ВГ-2026.46.06 | Прокладка изолирующая 375 × 280 × 3 | 1 | СТЭФ ГОСТ 12652-74 | 0,56 |
| 7 | ВГ-2026.46.07 | Втулка изолирующая Ø32/24,5 × 14 | 4 | СТЭФ ГОСТ 12652-74 | 0,01 |
| 8 | ВГ-2026.46.08 | Шайба изолирующая Ø50/25 × 3 | 4 | СТЭФ ГОСТ 12652-74 | 0,01 |
| 9 | ВГ-2026.46.09 | Лист подкладной 425 × 330 × 8 (ставится верфью при постройке) | 1 | АМг5 ГОСТ 21631-76 | 2,97 |
| 10 |  | Болт М24×80 А4-80 ГОСТ Р ИСО 4014-2013 | 4 |  | 0,40 |
| 11 |  | Гайка М24 самоконтрящаяся А4-80 ГОСТ Р 50273-92 | 4 |  | 0,11 |
| 12 |  | Шайба 24 увеличенная А4-80 ГОСТ 6958-78 | 4 |  | 0,05 |

### 3.2 3D модель узла

Корпус - 3D-модель конструктора в формате STEP, одно тело объёмом 961,6 см³ и массой 7,55 кг. Из неё взяты все размеры корпуса - опорные полосы хвоста, плечо под фитинг, центратор, отверстие, полость рукоятки и длина сварного шва 726 мм. Платик, запор, стержень и шайба подобраны по массе модели МКЭ 24,52 кг, её центру тяжести и моментам инерции. Масса стальных деталей узла - 24,20 кг, расхождение с моделью МКЭ -1,3 %. Виды модели - на рисунках 28 и 29.

Узел ВГ-2026.46.00, сборка

Рисунок 28 - Узел ВГ-2026.46.00, сборка

Узел ВГ-2026.46.00, взрыв-схема

Рисунок 29 - Узел ВГ-2026.46.00, взрыв-схема

### 3.3 Материалы с обоснованием выбора

Корпус - литая сталь 20ГСЛ, свариваемая, применяется для судового литья. Расчёт МКЭ выполнен для узла в сборе на принятых материалах - корпус 20ГСЛ, платик 09Г2С, запор 40Х (3.4). Наименьший запас по текучести корпуса при нагрузке расчёта - 3,83. Запас пропорционален пределу текучести, поэтому для других марок корпуса при той же геометрии он равен 3,83 × σт / 294. Сравнение материалов для корпуса:

Таблица 24

| Материал | Стандарт | σт, МПа | σв, МПа | δ, % | KCU, кДж/м² | Запас при 33,1 кН | Вывод |
|---|---|---|---|---|---|---|---|
| 20Л | ГОСТ 977-88 | 216 | 412 | 22 | 491 | 2,81 | запас по текучести на 27 % ниже 20ГСЛ, эксплуатационный случай не проходит |
| 25Л | ГОСТ 977-88 | 235 | 441 | 19 | 392 | 3,06 | ниже ударная вязкость, а узел работает на удар - посадка модуля краном |
| 20ГЛ | ГОСТ 977-88 | 275 | 540 | 18 | 491 | 3,58 | близка к 20ГСЛ, но предел текучести на 6 % ниже |
| 20ГСЛ | ГОСТ 977-88 | 294 | 540 | 18 | 491 | 3,83 | принято. Самая прочная из свариваемых литых сталей без закалки, судовое литьё, приварка к платику и заварка дефектов без подогрева |
| 35ХГСЛ | ГОСТ 977-88 | 343 | 590 | 14 | 294 | 4,46 | прочнее, но ударная вязкость ниже на 40 %, сварка с подогревом и повторной термообработкой |
| ВЧ 50 | ГОСТ 7293-85 | 320 | 500 | 7 | - | 4,16 | к платику не приварить, удлинение 7 %, хрупкость при ударе на морозе |
| 09Г2С | ГОСТ 19281-2014 | 300 | 450 | 21 | - | 3,90 | марки для литья в ГОСТ 977-88 нет. Корпус из проката - сварная конструкция из многих деталей |
| ВСт3сп5 | ГОСТ 14637-89 | 225 | 450 | 26 | - | 2,93 | то же, предел текучести на 23 % ниже 20ГСЛ |

Запирающий элемент - поковка 40Х КП 590 после улучшения, стержень - круг 40Х в улучшенном состоянии, платик - 09Г2С класса 325, шайба-подкова - тоже 09Г2С, режется плазмой в своём цехе без термообработки, крепёж - А4-80, изоляция - стеклотекстолит СТЭФ, подкладной лист - АМг5. **Сталь корпуса судна** - 09Г2С, сравнение с ВСт3сп5 и AH36. Расчётное напряжение общей прочности 78.4 МПа (прогиб на волне класса «М»). ВСт3сп5. Допускаемое 141 МПа - ниже расчётного. Чтобы пройти, связи нужно усилить на 38 %, масса корпуса вырастет с 896 до 1239 т. При этом экономии нет - 76.8 млн ₽ против 69.9 млн ₽ у 09Г2С - дешёвая сталь съедает выигрыш массой. AH36 прошла бы с запасом 172 % и дала бы 45 т экономии, но стоит 95.4 млн ₽ - на 36 % дороже, и срок поставки 8…12 недель. 09Г2С проходит с запасом 149 %, держит ударную вязкость при -40 °C (ледовые усиления «лёд 20») и есть на складе.

### 3.4 Расчёт на прочность узла

Нагрузки - от качки этого судна (приложение А.6). Период бортовой 3,26 с - самый короткий при осадках 1,20…1,30 м, крен на резонансе 19,8° без успокоителей (предельный случай, допускаемые 0,8σт) и 10,9° с цистернами (эксплуатация, 0,6σт), ось через ЦТ, ветер РКО класса «О». Расчётный модуль - самый тяжёлый из тем круизов, бассейн 13,5 т. Глубокий бассейн 18 т в темы не входит и на эти фундаменты не ставится. Модули тяжелее 10 т ставятся только в ряд ДП - в бортовом ряду к вертикальному ускорению от качки добавляется ε·y, и бассейн 13,5 т дал бы на опору 106,7 кН с запасом по МКЭ 1,19 при нужном 1,25, а в ДП - 88,5 кН и запас 1,43. Во всех темах бассейн стоит в ДП, предел по массе в бортовом ряду - 12,8 т.

Таблица 25

| Случай | Сжатие, кН | Отрыв, кН | Сдвиг, кН |
|---|---|---|---|
| Эксплуатация | 65,0 | 5,0 | 50,6 |
| Предельный | 88,5 | 26,2 | 89,5 |
| Посадка краном | 99,3 | - | - |
| Статика, вес модуля на 4 опоры | 33,1 | - | - |
| SWL опоры | 100 | 10 | 55 |

**Расчёт методом конечных элементов.** Узел в сборе - корпус 20ГСЛ, платик 09Г2С, запор 40Х - рассчитан в APM FEM для КОМПАС-3D v25, расчётное ядро APM Structure3D имеет аттестационный паспорт программы для ЭВМ № 488 от 19.12.2019, Ростехнадзор. Сетка - 10-узловые тетраэдры со стороной до 5 мм, 251 698 элементов, 420 713 узлов. Нагрузка - сила 33 100 Н вертикально вниз на плечо, вес модуля «бассейн» 13,5 т на четыре опоры, суммарная реакция закреплений равна нагрузке. Масса модели 24,52 кг, центр тяжести 0,31, 2,64, -41,42 мм. Результаты (рисунки 30 и 31):

Таблица 26

| Параметр | Значение |
|---|---|
| Эквивалентное напряжение по Мизесу, наибольшее, МПа | 191,8 |
| Суммарное перемещение, наибольшее, мм | 0,0028 |
| Запас по пределу текучести, наименьший | 3,83, на боковой грани корпуса |
| Запас по пределу прочности, наименьший | 6,93 |

Расчёт МКЭ, коэффициент запаса по пределу текучести

Рисунок 30 - Расчёт МКЭ, коэффициент запаса по пределу текучести

Расчёт МКЭ, суммарные перемещения, мм

Рисунок 31 - Расчёт МКЭ, суммарные перемещения, мм

Наименьшему запасу по текучести корпуса отвечает напряжение 294 / 3,83 = 76,9 МПа. На расчётное сжатие запас пересчитывается линейно, n = 3,83 × 33,1 / P:

Таблица 27

| Случай | Сжатие P, кН | Запас n | Нужно |
|---|---|---|---|
| Эксплуатация | 65,0 | 1,95 | 1,67 |
| Предельный | 88,5 | 1,43 | 1,25 |
| Посадка краном | 99,3 | 1,28 | 1,25 |

**Отрыв и сдвиг** отчёт МКЭ не покрывает, они проверены аналитически. Наименьший запас по каждому элементу:

Таблица 28

| Элемент | Случай | Значение | Допускается | Запас |
|---|---|---|---|---|
| Стержень поз. 2 Ø14 - изгиб при повороте | предельный | 371,2 МПа | 472,0 МПа | 1,27 |
| Балка Т 260 × 8 / 130 × 12 АМг5 - изгиб | эксплуатация | 52,1 МПа | 75,0 МПа | 1,44 |
| Болт М24 А4-80 - растяжение | предельный | 314,5 МПа | 480,0 МПа | 1,53 |
| Настил АМг5 под изолирующей шайбой - смятие | эксплуатация | 71,9 МПа | 112,5 МПа | 1,56 |
| Втулка изолирующая - смятие | предельный | 66,6 МПа | 110,0 МПа | 1,65 |
| Сдвиг платика - держит трение | эксплуатация | 50,6 кН | 84,0 кН | 1,66 |
| Шайба поз. 5 - изгиб кольца | предельный | 108,5 МПа | 260,0 МПа | 2,40 |
| Шайба поз. 5 - смятие буртом вала | предельный | 116,6 МПа | 357,5 МПа | 3,06 |
| Платик 09Г2С у болта - изгиб | предельный | 82,3 МПа | 260,0 МПа | 3,16 |
| Шов корпуса с платиком, катет 10 | предельный | 32,8 МПа | 135,2 МПа | 4,12 |
| Стык - нераскрытие | предельный | 21,2 кН | 90,5 кН | 4,27 |
| Бурт вала - срез | предельный | 63,3 МПа | 271,4 МПа | 4,29 |
| Болт М24 - срез при проскальзывании | предельный | 63,4 МПа | 276,0 МПа | 4,35 |
| Шайба поз. 5 - срез по кромке отверстия корпуса | предельный | 30,5 МПа | 149,5 МПа | 4,91 |
| Вал поз. 3 - растяжение по отверстию | предельный | 91,4 МПа | 472,0 МПа | 5,16 |
| Конус-голова - изгиб лепестка | предельный | 74,0 МПа | 472,0 МПа | 6,38 |
| Вал поз. 3 - растяжение по проточке | предельный | 69,0 МПа | 472,0 МПа | 6,84 |
| Центратор - смятие о стенку отверстия фитинга | предельный | 39,9 МПа | 323,4 МПа | 8,11 |
| Стержень поз. 2 - смятие в отверстии вала | предельный | 54,8 МПа | 649,0 МПа | 11,85 |
| Низ корпуса 20ГСЛ - смятие шайбой | предельный | 26,4 МПа | 323,4 МПа | 12,27 |
| Конус-голова 40Х - смятие днища фитинга | предельный | 14,7 МПа | 302,5 МПа | 20,55 |

Проверок узла (качка, прочность, литьё, цех, сроки, себестоимость) - 62, не выполнено 0.

## 4 Технология и организация производства
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

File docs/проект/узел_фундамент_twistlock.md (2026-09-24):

# Узел КД. Фундамент-замок модуля - ВГ-2026.46.00

> Проверок узла 62, не выполнено 0.

## 1. Узел и его устройство

Узлом КД выбран фундамент для крепления модульных номеров солнечной палубы - твистлок типа «ласточкин хвост». Он держит «трансформер» - 7 типов модулей в темах круизов на 18 слотах, на судно 72 фундамента. Узел собирается из четырёх основных деталей и шайбы-подковы и выпускается как самостоятельное производство в арендованном цехе рядом с верфью. С экономикой судна узел связан одной цифрой - себестоимостью за штуку (раздел 11).

- **Корпус (поз. 1)** - отливка из стали 20ГСЛ, габарит 175 × 160 × 76 мм, масса 7,55 кг по 3D-модели. Снизу две опорные полосы «ласточкина хвоста» с гранями под 35° к вертикали, ими корпус лежит на платике и приварен к нему. Сверху плечо площадью 102 см², на которое садится угловой фитинг контейнера, и центратор 60 × 116 × 30 мм - он входит в отверстие фитинга 124,5 × 63,5 по ISO 1161 и принимает сдвиг. Через корпус проходит отверстие Ø30 под вал запора, внутри - полость рукоятки и передняя прорезь с двумя вырезами-фиксаторами на 74° друг от друга.
- **Элемент запирающий, конус-голова (поз. 3)** - поковка из стали 40Х. Голова 104 × 54 мм проходит отверстие фитинга в положении «открыто» и повёрнутая на 74° держит фитинг лепестками. Вал Ø30 вставляется в корпус сверху.
- **Стержень (поз. 2)** - рукоятка Ø14 × 127 мм из круга 40Х. Заводится через прорезь корпуса в поперечное отверстие вала, ввёртывается в него резьбой М14×1,5 на анаэробном фиксаторе и поворачивает запор на 74° от выреза до выреза.
- **Шайба разрезная, подкова (поз. 5)** - Ø50 × 12 мм из листа 09Г2С, стоит в проточке вала Ø22 под корпусом и опирается на низ корпуса вокруг отверстия по всему кругу. Отрыв идёт с бурта вала через шайбу на корпус, стержень поз. 2 только поворачивает запор. В полости рукоятки шайба не помещается - свод полости есть только со стороны рукоятки, а высота 15 мм занята стержнем. Шайба заводится снизу через окно 110 × 60 мм в платике, разрез - на ширину проточки.
- **Платик (поз. 4)** - лист 09Г2С 375 × 280 × 20 мм с четырьмя овальными отверстиями 26 × 45 под болты М24 и окном 110 × 60 мм под шайбу. Корпус приварен к нему угловыми швами катетом 10 мм длиной 726 мм.
- **Крепление к палубе.** Настил солнечной палубы - алюминиевый сплав АМг5, стальной платик к нему не приварить. Поэтому платик ставится на подкладной лист АМг5 425 × 330 × 8 мм, приваренный к настилу над подпалубной балкой Т 260 × 8 / 130 × 12, через прокладку из стеклотекстолита. Болты М24 А4-80 стоят в изолирующих втулках, сталь и алюминий не касаются.
- **Высота опоры 77 мм** от настила до низа фитинга - хвост 46, платик 20, прокладка 3, подкладной лист 8 мм.

Узел ВГ-2026.46.00, сборка

*Узел ВГ-2026.46.00, сборка*
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

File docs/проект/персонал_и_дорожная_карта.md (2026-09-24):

# Персонал и дорожная карта постройки (24.09.2026)

Исходные данные - методика расчёта численности, оргструктура верфи и исходная дорожная карта (редакция 4 от 23.09.2026). Методика применена к нашему судну, исходная карта взята за базу, а что в ней не сходится - вынесено в замечания.

## 1. Трудоёмкость по методике коллег на наше судно
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

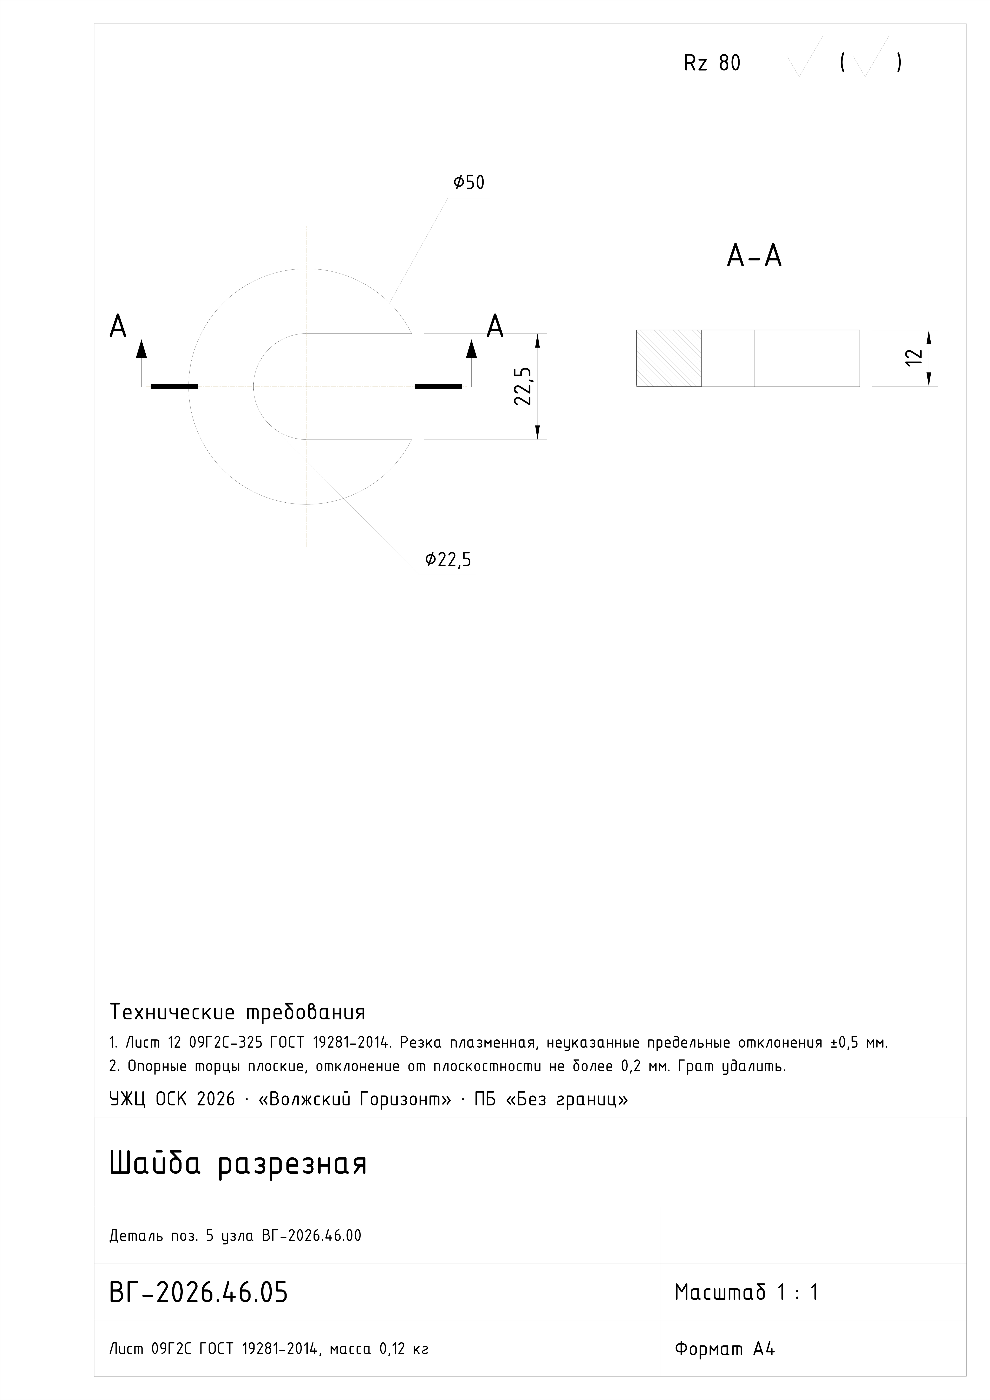
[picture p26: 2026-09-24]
renders/горизонт_2026/чертежи_dxf/ВГ-2026_46_05_шайба.png

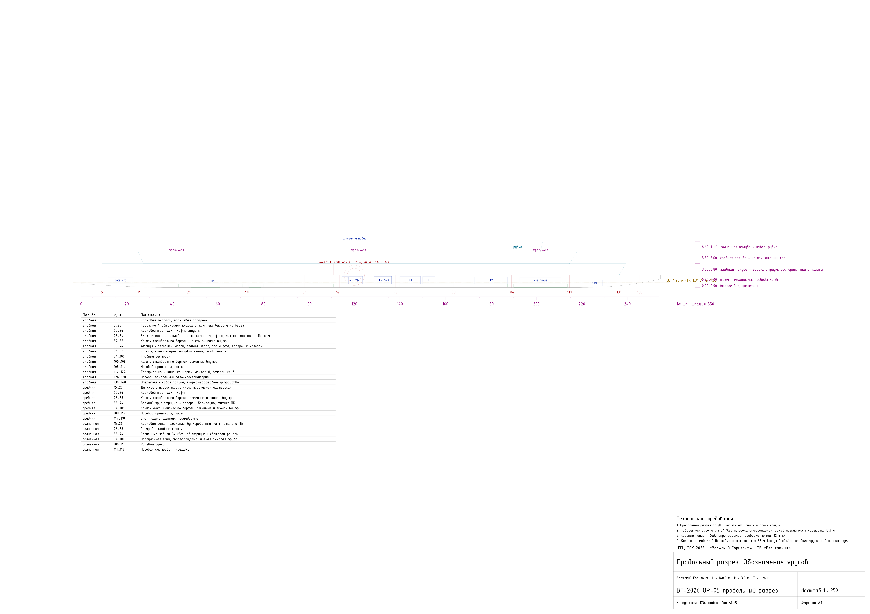
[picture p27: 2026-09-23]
renders/горизонт_2026/чертежи_dxf/ВГ-2026_ОР-05_продольный_разрез.png

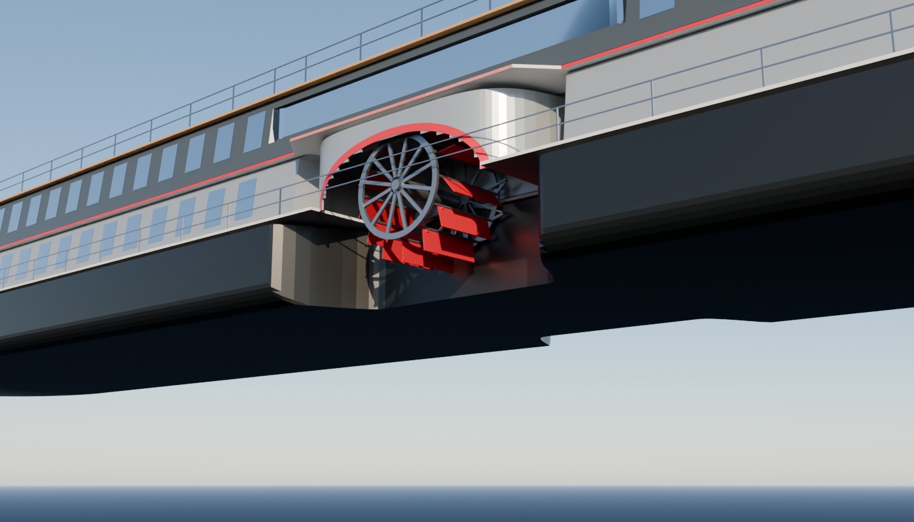
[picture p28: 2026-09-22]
renders/горизонт_2026/проверка/05_ниша_снизу.jpg

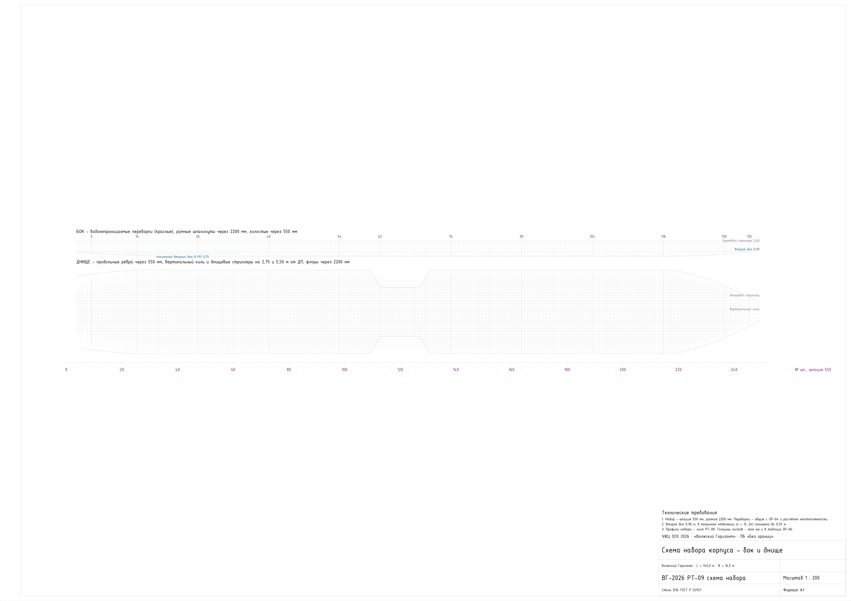
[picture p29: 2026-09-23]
renders/горизонт_2026/чертежи_dxf/ВГ-2026_РТ-09_схема_набора.png

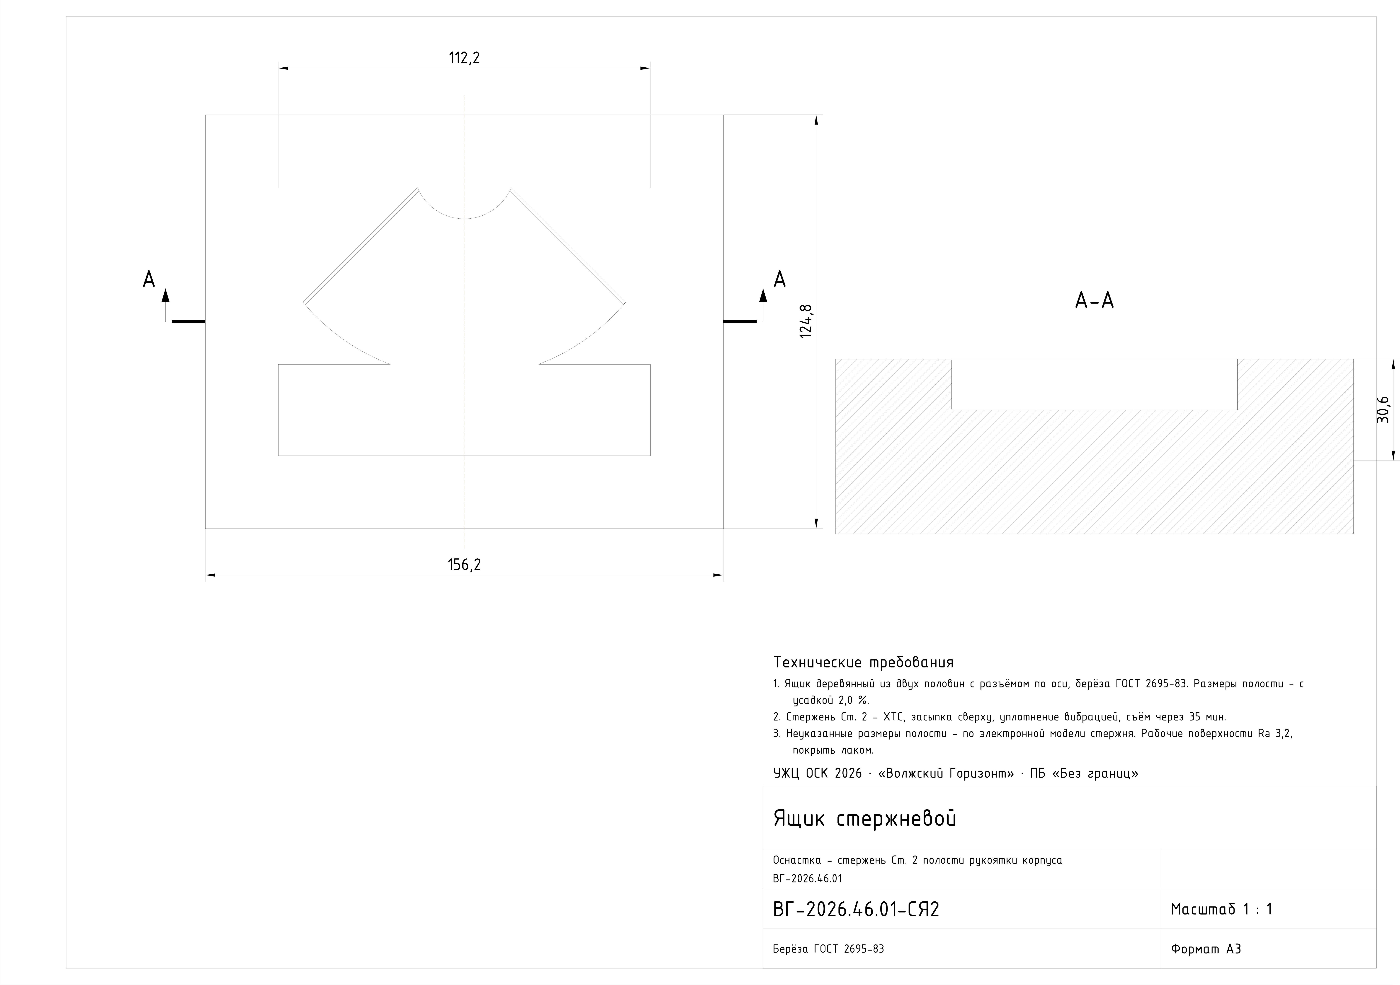
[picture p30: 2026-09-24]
renders/горизонт_2026/чертежи_dxf/ВГ-2026_46_01-СЯ2_ящик_стержневой.png

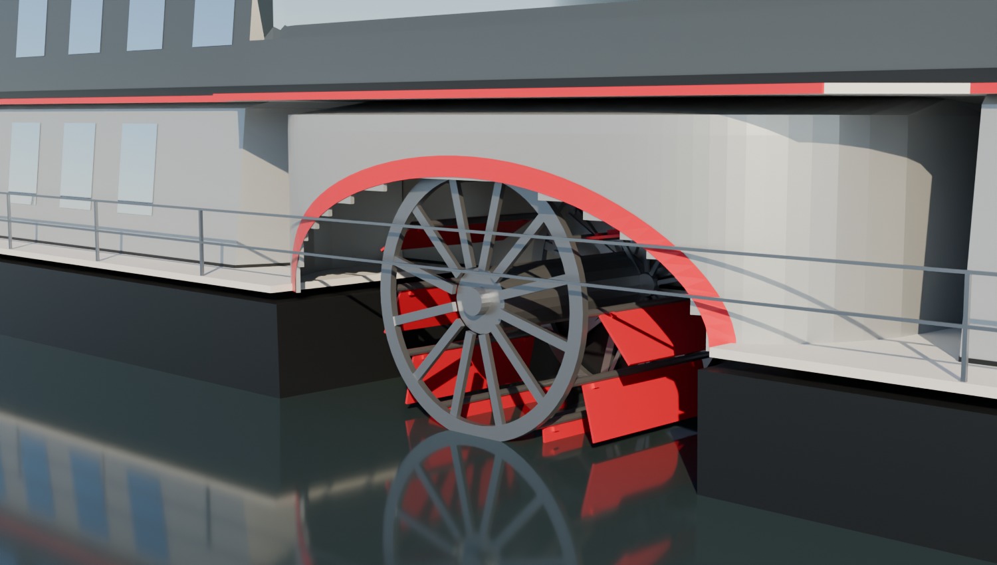
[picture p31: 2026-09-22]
renders/горизонт_2026/проверка/01_колесо.jpg

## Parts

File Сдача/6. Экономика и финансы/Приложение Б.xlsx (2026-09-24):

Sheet: Калькуляция
Калькуляция себестоимости и цены головного судна, руб.
Статья | Всего | 2027 | 2028 | 2029 | Примечание
Материальные затраты | 586962237.7 | 586962237.7 | 0 | 0
сырьё, материалы, вспомогательные материалы | 227808679.4 | 227808679.4 | 0 | 0 | закупка по договорам 2027 года
покупные комплектующие изделия | 352767223.4 | 352767223.4 | 0 | 0 | технико-коммерческие предложения
транспортно-заготовительные расходы | 6386334.93 | 6386334.93 | 0 | 0
Затраты на оплату труда | 816683534 | 67424018.12 | 458218857 | 291040658.8
основная заработная плата | 720431546.1 | 59477615.99 | 404214491.8 | 256739438.3
дополнительная заработная плата | 96251987.93 | 7946402.136 | 54004365.29 | 34301220.5
Страховые взносы | 267872199.1 | 22115077.94 | 150295785.1 | 95461336.09
Общепроизводственные затраты | 325685529.7 | 30101499.22 | 140856324.9 | 154727705.7 | руководство производством, обучение
Общехозяйственные затраты | 208584004.8 | 30027121.04 | 85088718.69 | 93468165.05 | инженерная и управленческая группа
Производственная себестоимость | 2205787505 | 736629954 | 834459685.7 | 634697865.6
Коммерческие расходы | 15040906.52 | 4223798.461 | 5206516.102 | 5610591.958 | маркетинг, связи с общественностью
Полная себестоимость | 2220828412 | 740853752.4 | 839666201.8 | 640308457.6
Прибыль | 333124261.8 |  |  |  | рентабельность к полной себестоимости
Цена судна без НДС | 2553952674
НДС | 561869588.2
Цена судна с НДС | 3115822262
Трудоёмкость, н·ч | 611468.9978 | 54764.96891 | 343628.9473 | 213075.0816

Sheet: Исходные
Исходные данные расчёта
Параметр | Значение | Ед. | Основание
НДС | 22.0% | % | с 2026 года
Транспортно-заготовительные расходы от материалов и ПКИ | 1.1% | % | норматив верфи
Коэффициент использования металла | 0.85 |  | корпус и надстройка, 0,80…0,90
Масса корпуса металлического, сталь D36 | 806.6 | т | нагрузка масс проекта
Масса надстройки и рубки, АМг5 | 136.3 | т | нагрузка масс проекта
Коэффициент выполнения норм | 1.05 |  | Приказ Минпромторга № 822
Коэффициент головного судна к серийному | 1.30 |  | Приказ Минпромторга № 958, прил. 7
Премия АУП и ИТР к окладу | 10.0% | % | положение об оплате труда
Фонд рабочего времени в месяц | 164.7 | ч | 247 рабочих дней × 8 ч / 12
Рентабельность к полной себестоимости | 15.0% | % | принята для гражданского судна
Ставка дисконтирования | 15.0% | % | ключевая ставка Банка России с премией за риск
Серийных судов после головного, по одному в год | 5 | шт. | рынок принимает до 21 судна
Рост цен после 2029 года | 6.0% | % в год | прогноз инфляции
Индекс цен и оплаты труда 2026 | 1.000 |  | базовый год
Индекс цен и оплаты труда 2027 | 1.081 |  | прогноз
Индекс цен и оплаты труда 2028 | 1.155 |  | прогноз
Индекс цен и оплаты труда 2029 | 1.235 |  | прогноз

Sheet: ДЗП
Дополнительная заработная плата
Наименование | Дней в году
Ежегодный основной и дополнительный отпуск | 28
Временная нетрудоспособность | 3
Медицинское обследование, донорские дни и отдых после них | 2
Итого | 33
База - рабочих дней в году | 247
ДЗП к основной заработной плате | 13.4%

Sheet: Взносы
Страховые взносы
Вид страхования | Ставка
Обязательное пенсионное страхование | 22.0%
Обязательное медицинское страхование | 5.1%
Временная нетрудоспособность и материнство | 2.9%
От несчастных случаев на производстве и профзаболеваний, по ОКВЭД | 2.8%
Итого | 32.8%

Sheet: Материалы
Сырьё, материалы и вспомогательные материалы
Наименование | Ед. | Количество | Доля в группе | Цена за ед. с НДС, 2026 | Индекс к 2027 | Цена за ед. без НДС, 2027 | Сумма, руб. | Поставщик | Сайт
Лист судостроительный 10×1600×6000, категория D36 | т | 521.0 | 54.9% | 70000 | 1.052 | 60360.66 | 31450873.3 | АО «Металлсервис» | mc.ru
Лист стальной 24×2000×6000, D36 ГОСТ Р 52927-2015 | т | 43.4 | 4.6% | 45011 | 1.052 | 38812.76 | 1685280.069 | торговая площадка «Пульс цен» | pulscen.ru
Лист низколегированный 6×1500×6000, 09Г2С-15 | т | 199.7 | 21.0% | 70990 | 1.052 | 61214.33 | 12226676.76 | АО «Металлсервис» | mc.ru
Швеллер 12П, 09Г2С-15, длина 12 м | т | 184.7 | 19.5% | 112490 | 1.052 | 96999.57 | 17919278.02 | АО «Металлсервис» | mc.ru
Лист АМг5М 6×1500×4000 | т | 129.5 | 80.7% | 700000 | 1.043 | 598442.62 | 77484872.75 | ООО «Невская Алюминиевая Компания» | spbalum.ru
Тавр АМг5 20×20×2 ГОСТ 13622-91 | т | 22.9 | 14.3% | 296060 | 1.052 | 255291.08 | 5848096.55 | «Металл-союз» | metsklad.ru
Уголок АМг5 50×30×3 | т | 4.8 | 3.0% | 1600000 | 1.052 | 1379672.13 | 6595810.706 | ПКФ «Металл СВ» | sv-metal.ru
Уголок АМг5 40×25×4 | т | 3.2 | 2.0% | 408500 | 1.052 | 352247.54 | 1122661.947 | Компания «Мост» | moststal.ru
Труба бесшовная DN40…DN125, Ст20 и 09Г2С, ГОСТ 8732 | т | 75.4 |  | 158870 | 1.040 | 135430.16 | 10211434.36 | ООО МК «Буран» | buranmetall.ru
Труба бесшовная DN20…DN80, 12Х18Н10Т | т | 38.1 |  | 811000 | 1.040 | 691344.26 | 26340216.39 | ООО ТК «ИноксМаркет» | inoxmarket.ru
Труба ПНД и ПП DN50…DN225, судовая негорючая | км | 8.9 |  | 205000 | 1.040 | 174754.10 | 1555311.475 | компания «Энерго Пайп» | energo-pipe.ru
Судовая арматура, фланцы, клапаны с уплотнением PTFE для метанола | шт. | 50.0 |  | 12684 | 1.042 | 10833.38 | 541669.1803 | ООО «ТД Ватервальве» | shop-watervalve.ru
Кабель силовой, контрольный, огнестойкий, слаботочный | км | 55.0 |  | 49800 | 1.042 | 42534.10 | 2339375.41 | ООО «СнабКабель» | snabcable.ru
Кабельные трассы (лотки), сальники, проходки | км | 25.0 |  | 470640 | 1.042 | 401972.85 | 10049321.31 | АО «ДКС» | dkc.ru
Грунт эпоксидный и покрытие Foul Release для пресной воды | компл. | 1700.0 |  | 978 | 1.039 | 832.90 | 1415935.574 | ГК «ДЖИФЛЕКС» | gflex.ru
Грунт и полиуретановая эмаль, стойкая к УФ | кг | 8800.0 |  | 2805 | 1.039 | 2388.85 | 21021865.57 | магазин красок «Колор» | color1.ru
Итого материалы |  |  |  |  |  |  | 227808679.4

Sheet: ПКИ
Покупные комплектующие изделия
Наименование | Ед. | Кол. | Цена за ед. без НДС, руб. | Сумма, руб. | Поставщик | Основание
Оборудование дизель-электрического комплекса - три двухтопливных дизель-генератора 600 кВт (дизель, метанол), ГРЩ, гребные электродвигатели колёс 2 × 550 кВт, преобразователи | компл. | 1 | 67580000.00 | 67580000 | Weichai Power Co., Ltd. (Marine Division) | ТКП № 1
Гребные колёса с механизмом поворота плиц и сопутствующее оборудование | компл. | 1 | 13500000.00 | 13500000 | ООО «Плато-Инжиниринг» | ТКП № 2
Оборудование и арматура общесудовых систем и систем СЭУ | компл. | 1 | 36800000.00 | 36800000 | ООО «Промтехнологии» | ТКП № 3
Система вентиляции и кондиционирования воздуха | компл. | 1 | 228000000.00 | 228000000 | поставщик по ТКП № 4 | ТКП № 4
Фундаменты-замки модулей солнечной палубы ВГ-2026.46.00 (твистлок «ласточкин хвост»), с ЗИП и испытаниями | шт. | 72 | 95655.88 | 6887223.36 | цех узла верфи | себестоимость узла
Итого ПКИ |  |  |  | 352767223.4

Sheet: Трудоёмкость
Трудоёмкость постройки головного судна
Вид работ | Трудоёмкость, чел·ч | Трудоёмкость, н·ч | Доля 2027 | Доля 2028 | Доля 2029 | н·ч 2027 | н·ч 2028 | н·ч 2029 | Задачи дорожной карты
Обработка деталей корпуса | 33749.91221 | 35437.40783 | 31.1% | 68.9% | 0.0% | 11037.88113 | 24399.5267 | 0 | 10.1. Корпусообработка, изготовление деталей
Предварительная сборка конструкций | 81396.84711 | 85466.68946 | 31.1% | 68.9% | 0.0% | 26620.77213 | 58845.91733 | 0 | 10.2. Сборка и сварка секций и блоков
Формирование корпуса на стапеле | 94632.1068 | 99363.71214 | 0.0% | 100.0% | 0.0% | 0 | 99363.71214 | 0 | 10.4.1. Формирование корпуса на стапеле
Трубомонтажные работы | 46985.17191 | 49334.4305 | 0.0% | 50.7% | 49.3% | 0 | 25031.03848 | 24303.39202 | 10.4.3. Монтаж трубопроводов, 11. Работы на достроечной набережной (монтаж оборудования и систем, отделка), пуско-наладочные работы
Механомонтажные работы | 41691.06803 | 43775.62143 | 0.0% | 50.7% | 49.3% | 0 | 22210.63978 | 21564.98165 | 10.4.2. Монтаж механизмов, 11. Работы на достроечной набережной (монтаж оборудования и систем, отделка), пуско-наладочные работы
Достроечные работы | 107867.3665 | 113260.7348 | 0.0% | 31.8% | 68.2% | 0 | 36058.51966 | 77202.21516 | 11. Работы на достроечной набережной (монтаж оборудования и систем, отделка), пуско-наладочные работы
Испытания судна | 49632.22385 | 52113.83504 | 0.0% | 0.0% | 100.0% | 0 | 0 | 52113.83504 | 12. Швартовные испытания, 13. Устранение ошибок по результатам швартовных испытаний, 14. Заводские ходовые испытания, 15. Устранение ошибок по результатам заводских ходовых испытаний
Изготовление изделий МСЧ | 73455.69129 | 77128.47586 | 22.2% | 77.8% | 0.0% | 17106.31566 | 60022.1602 | 0 | 10.3. Изготовление изделий МСЧ
Электромонтажные работы | 52941.03877 | 55588.09071 | 0.0% | 31.8% | 68.2% | 0 | 17697.43296 | 37890.65775 | 11. Работы на достроечной набережной (монтаж оборудования и систем, отделка), пуско-наладочные работы
Итого | 582351.4265 | 611468.9978 |  |  |  | 54764.96891 | 343628.9473 | 213075.0816
Трудоёмкость по Приказу Минпромторга № 958 на водоизмещение порожнем, чел·ч × коэффициент выполнения норм = нормо-часы. Доли по годам - по рабочим дням задач дорожной карты.

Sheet: ФОТ
Фонд оплаты труда основных производственных рабочих
Год | Вид работ | н·ч | Стоимость н·ч 2026, руб. | Индекс | Стоимость н·ч, руб. | Основная ЗП, руб. | ДЗП, руб. | Взносы, руб.
2027 | Обработка деталей корпуса | 11037.88113 | 1043.15 | 1.081 | 1127.65 | 12446813.12 | 1662934.546 | 4627997.234
2027 | Предварительная сборка конструкций | 26620.77213 | 1043.15 | 1.081 | 1127.65 | 30018784.58 | 4010606.847 | 11161640.39
2027 | Изготовление изделий МСЧ | 17106.31566 | 919.97 | 1.081 | 994.49 | 17012018.29 | 2272860.743 | 6325440.323
2028 | Обработка деталей корпуса | 24399.5267 | 1043.15 | 1.155 | 1204.84 | 29397483.05 | 3927598.95 | 10930626.9
2028 | Предварительная сборка конструкций | 58845.91733 | 1043.15 | 1.155 | 1204.84 | 70899812.06 | 9472444.526 | 26362100.16
2028 | Формирование корпуса на стапеле | 99363.71214 | 1043.15 | 1.155 | 1204.84 | 119717201 | 15994605.81 | 44513472.65
2028 | Трубомонтажные работы | 25031.03848 | 1146.25 | 1.155 | 1323.92 | 33139061.18 | 4427485.907 | 12321827.45
2028 | Механомонтажные работы | 22210.63978 | 1146.25 | 1.155 | 1323.92 | 29405082.46 | 3928614.255 | 10933452.52
2028 | Достроечные работы | 36058.51966 | 909.05 | 1.155 | 1049.95 | 37859741.87 | 5058184.137 | 14077079.73
2028 | Изготовление изделий МСЧ | 60022.1602 | 919.97 | 1.155 | 1062.57 | 63777467.66 | 8520876.246 | 23713856.8
2028 | Электромонтажные работы | 17697.43296 | 979.36 | 1.155 | 1131.16 | 20018642.42 | 2674555.466 | 7443368.908
2029 | Трубомонтажные работы | 24303.39202 | 1146.25 | 1.235 | 1415.62 | 34404337.43 | 4596530.911 | 12792284.82
2029 | Механомонтажные работы | 21564.98165 | 1146.25 | 1.235 | 1415.62 | 30527792.37 | 4078611.936 | 11350900.61
2029 | Достроечные работы | 77202.21516 | 909.05 | 1.235 | 1122.68 | 86673132.01 | 11579811.16 | 32226965.36
2029 | Испытания судна | 52113.83504 | 921.45 | 1.235 | 1137.99 | 59305062.22 | 7923348.394 | 22050918.68
2029 | Электромонтажные работы | 37890.65775 | 979.36 | 1.235 | 1209.51 | 45829114.3 | 6122918.104 | 17040266.63
Год | Итого | н·ч |  |  |  | Основная ЗП, руб. | ДЗП, руб. | Взносы, руб.
2027 | Итого за год | 54764.96891 |  |  |  | 59477615.99 | 7946402.136 | 22115077.94
2028 | Итого за год | 343628.9473 |  |  |  | 404214491.8 | 54004365.29 | 150295785.1
2029 | Итого за год | 213075.0816 |  |  |  | 256739438.3 | 34301220.5 | 95461336.09

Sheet: АУП и ИТР
Административно-управленческий персонал и ИТР проекта
Должность | Чел. | Оклад, руб./мес, 2026 | Категория | Статья | Основная ЗП с премией, руб./мес | ДЗП, руб./мес | Взносы, руб./мес | Итого, руб./мес | Месяцев 2027 | Месяцев 2028 | Месяцев 2029 | Затраты 2027, руб. | Затраты 2028, руб. | Затраты 2029, руб.
Заместитель главного инженера | 1 | 130000 | АУП | ОХР | 143000 | 19105.26316 | 53170.52632 | 215275.7895 | 4.5 | 12.0 | 12.4 | 1055006.955 | 2989603.63 | 3284016.61
Ведущий конструктор | 4 | 170000 | ИТР | ОХР | 748000 | 99935.22267 | 278122.753 | 1126057.976 | 4.5 | 12.0 | 12.4 | 5518497.921 | 15637926.68 | 17177933.04
Ведущий технолог | 4 | 100000 | ИТР | ОХР | 440000 | 58785.4251 | 163601.6194 | 662387.0445 | 4.5 | 12.0 | 12.4 | 3246175.247 | 9198780.399 | 10104666.49
Ведущий специалист технического контроля | 3 | 150000 | ИТР | ОХР | 495000 | 66133.60324 | 184051.8219 | 745185.4251 | 4.5 | 12.0 | 12.4 | 3651947.153 | 10348627.95 | 11367749.8
Ведущий экономист | 2 | 120000 | АУП | ОХР | 264000 | 35271.25506 | 98160.97166 | 397432.2267 | 4.5 | 12.0 | 12.4 | 1947705.148 | 5519268.239 | 6062799.895
Ведущий инженер-технолог | 4 | 150000 | ИТР | ОХР | 660000 | 88178.13765 | 245402.4291 | 993580.5668 | 4.5 | 12.0 | 12.4 | 4869262.871 | 13798170.6 | 15156999.74
Инженер-конструктор 1 категории | 4 | 150000 | ИТР | ОХР | 660000 | 88178.13765 | 245402.4291 | 993580.5668 | 4.5 | 12.0 | 12.4 | 4869262.871 | 13798170.6 | 15156999.74
Технолог 1 категории | 5 | 120000 | ИТР | ОХР | 660000 | 88178.13765 | 245402.4291 | 993580.5668 | 4.5 | 12.0 | 12.4 | 4869262.871 | 13798170.6 | 15156999.74
Начальник производства | 1 | 200000 | АУП | ОПР | 220000 | 29392.71255 | 81800.80972 | 331193.5223 | 2.6 | 12.0 | 12.4 | 929158.857 | 4599390.199 | 5052333.246
Начальник участка | 5 | 170000 | ИТР | ОПР | 935000 | 124919.0283 | 347653.4413 | 1407572.47 | 2.6 | 12.0 | 12.4 | 3948925.142 | 19547408.35 | 21472416.29
Старший мастер участка | 7 | 180000 | ИТР | ОПР | 1386000 | 185174.0891 | 515345.1012 | 2086519.19 | 2.6 | 12.0 | 12.4 | 5853700.799 | 28976158.26 | 31829699.45
Мастер участка | 7 | 130000 | ИТР | ОПР | 1001000 | 133736.8421 | 372193.6842 | 1506930.526 | 2.6 | 12.0 | 12.4 | 4227672.8 | 20927225.41 | 22988116.27
Специалист по охране труда | 2 | 120000 | ИТР | ОПР | 264000 | 35271.25506 | 98160.97166 | 397432.2267 | 2.6 | 12.0 | 12.4 | 1114990.628 | 5519268.239 | 6062799.895
Специалист по МТО | 2 | 150000 | ИТР | ОПР | 330000 | 44089.06883 | 122701.2146 | 496790.2834 | 2.6 | 12.0 | 12.4 | 1393738.286 | 6899085.299 | 7578499.869
Наладчик систем | 10 | 100000 | ИТР | ОПР | 1100000 | 146963.5628 | 409004.0486 | 1655967.611 | 2.6 | 12.0 | 12.4 | 4645794.285 | 22996951 | 25261666.23
Кладовщик | 7 | 75000 | ВПР | ОПР | 577500 | 77155.87045 | 214727.1255 | 869382.996 | 2.6 | 12.0 | 12.4 | 2439042 | 12073399.27 | 13262374.77
Строитель кораблей | 7 | 120000 | ИТР | ОПР | 924000 | 123449.3927 | 343563.4008 | 1391012.794 | 2.6 | 12.0 | 12.4 | 3902467.2 | 19317438.84 | 21219799.63
Специалист по связям с общественностью | 2 | 80000 | служащий | КОМ | 176000 | 23514.17004 | 65440.64777 | 264954.8178 | 10.2 | 12.0 | 12.4 | 2926262.324 | 3679512.159 | 4041866.597
Итого | 77 |  |  |  |  |  |  | 16534836.6 |  |  |  | 61408873.36 | 229624555.7 | 252237737.3
Общепроизводственные (руководство производством) |  |  |  | ОПР |  |  |  |  |  |  |  | 28455490 | 140856324.9 | 154727705.7
Общехозяйственные (инженерная и управленческая группа) |  |  |  | ОХР |  |  |  |  |  |  |  | 30027121.04 | 85088718.69 | 93468165.05
Коммерческие (связи с общественностью) |  |  |  | КОМ |  |  |  |  |  |  |  | 2926262.324 | 3679512.159 | 4041866.597
Месяцы - от формирования проектной группы (ОХР), от начала корпусообработки (ОПР), от подписания договора (коммерческие) до передачи судна заказчику, по дорожной карте.

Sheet: Обучение
Обязательное обучение персонала
Организация | Тема | Стоимость 2026, руб. | Индекс | Стоимость 2027, руб. | Человек | Итого, руб.
АНО ДПО «Учебный центр «Перспектива» | Эксплуатация электроустановок для испытаний и измерений | 4200.00 | 1.040 | 4368.00 | 30 | 131040
АНО ДПО «Прикамский институт безопасности» | Поверка и калибровка средств измерений теплотехнических величин | 8000.00 | 1.040 | 8320.00 | 15 | 124800
АНО ДПО «ДВИПРАЗ» | Поверка и калибровка средств геометрических измерений | 526.00 | 1.040 | 547.04 | 25 | 13676
ЧОУ ДПО «Учебный центр «Конфакт» | Проверка знаний машиниста плавучего крана | 2000.00 | 1.040 | 2080.00 | 35 | 72800
ЧОУ ДПО «Морские системы» | Подготовка по разделу A-VI/1 Кодекса ПДНВ | 7300.00 | 1.040 | 7592.00 | 20 | 151840
ООО МУИЦ «Меркурий» | Специалист по пожарной профилактике | 350.00 | 1.040 | 364.00 | 100 | 36400
ЧОУ ДПО «Спутник» | Техносферная безопасность, охрана труда | 808.00 | 1.040 | 840.32 | 150 | 126048
ЧОУ ДПО «Морские системы» | Специалист по спасательным шлюпкам и плотам, раздел A-VI/2 Кодекса ПДНВ | 3000.00 | 1.040 | 3120.00 | 30 | 93600
ИП Климчук В. А. | Обучение по охране труда, общий договор | 376800.00 | 1.040 | 391872.00 | договор | 391872
ИП Лысенко И. М. | Обучение по электробезопасности, общий договор | 178020.00 | 1.041 | 185318.82 | договор | 185318.82
АНО ДПО «ПРОФАТОМЭНЕРГО» | Обучение по радиационной безопасности, общий договор | 306360.00 | 1.040 | 318614.40 | договор | 318614.4
Итого |  |  |  |  |  | 1646009.22

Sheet: Маркетинг
Маркетинг и продвижение
Исполнитель | Вид | Руб. в месяц | Как выполняется
Метрополитен Санкт-Петербурга | Реклама на путевых щитах 4 × 2 м | 124000 | макет - отдел по связям с общественностью верфи
АО «Адмиралтейские верфи» | Буклеты и раздаточная продукция | 3000 | типография предприятия, 100 буклетов А4 в месяц по 30 руб., выставки и конференции
АО «Адмиралтейские верфи» | Реклама в социальных сетях | 0 | силами сотрудников в Telegram, MAX и ВКонтакте
Итого в месяц |  | 127000
Год | Месяцев от договора до передачи судна | Затраты, руб.
2027 | 10.2 | 1297536.137
2028 | 12.0 | 1527003.942
2029 | 12.4 | 1568725.361

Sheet: НИОКР
НИОКР - проектирование судна проектным бюро
Ставка инженера-конструктора с премией, ДЗП и взносами, руб./ч | 1508.47
Стадия | Трудоёмкость, чел·ч | Задача дорожной карты | Доля 2026 | Доля 2027 | Затраты 2026, руб. | Затраты 2027, руб. | Итого, руб.
Эскизный проект | 1628.955039 | 3.2. Эскизирование | 100.0% | 0.0% | 2457233.913 | 0 | 2457233.913
Технический проект | 6515.820156 | 3.4. ОКР (опытно-конструкторская работа) | 65.0% | 35.0% | 6388808.175 | 3718777.805 | 10107585.98
Рабочая КД | 24434.32559 | 6. Составление рабочей конструкторской документации (схемы систем, чертежи) | 0.0% | 100.0% | 0 | 39844047.91 | 39844047.91
Итого | 32579.10078 |  |  |  | 8846042.088 | 43562825.71 | 52408867.8

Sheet: Капзатраты
Капитальные затраты - цех фундаментов-замков в арендованном ангаре
Оборудование (покупка) | Кол. | Цена, руб. | Сумма, руб.
Печь индукционная тигельная ИСТ-0,16 с преобразователем частоты и градирней | 1 | 6800000 | 6800000
Ковш разливочный чайниковый 0,25 т и стенд подогрева | 1 | 380000 | 380000
Смеситель ХТС лопастной 0,1 м³ | 1 | 450000 | 450000
Стол вибрационный формовочный 1,0 × 1,0 м | 1 | 220000 | 220000
Опоки сварные 600 × 400 × 160/80 со штырями | 8 | 25000 | 200000
Решётка выбивная инерционная | 1 | 320000 | 320000
Пневмошлифмашины угловые DAEWOO (круг 180 мм) и прямые Daewoo DG-38LS | 5 | 18000 | 90000
Компрессор винтовой 11 кВт, 1,6 м³/мин, 8 бар, с ресивером | 1 | 650000 | 650000
Электропечь камерная сопротивления ПН-12-2 | 1 | 950000 | 950000
Машина плазменной резки с ЧПУ NUMOREX NXB, поле 2000 × 6000 мм, источник 125 А | 1 | 4800000 | 4800000
Станок вертикально-сверлильный 2Н135 | 1 | 950000 | 950000
Станок токарно-винторезный 16К20, РМЦ 1000 | 1 | 2900000 | 2900000
Полуавтомат сварочный 400 А, стол сварочный, фильтровентиляционный агрегат | 1 | 420000 | 420000
Камера окрасочно-сушильная тупиковая 3 × 3 × 2,5 м, подогрев до 110 °С | 1 | 1450000 | 1450000
Верстаки слесарные и сборочные | 3 | 30000 | 90000
Стол контроля, плита поверочная, мерительный инструмент, твердомер, толщиномер, шаблоны | 1 | 280000 | 280000
Вентиляция литейного участка - зонт над печью, отсосы обрубки | 1 | 900000 | 900000
Стеллажи, поддоны, тележки гидравлические | 1 | 220000 | 220000
Итого оборудование |  |  | 22070000
Площадка | м² | Руб./м² в месяц | Месяцев
Аренда ангара под цех узла | 864 | 650 | 3.6
Аренда за срок, руб. |  |  | 2021760
Судно строится на действующих мощностях верфи: стапель, достроечная набережная, цеха. Аренда ангара входит в себестоимость фундаментов-замков.

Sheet: Безубыточность
Серийное судно и точка безубыточности
Показатель | Значение | Примечание
Материальные затраты, руб. | 586962237.7 | как у головного
Оплата труда с взносами головного, руб. | 1084555733
Оплата труда с взносами серийного, руб. | 834273640.9 | без коэффициента головного
Прямые затраты серийного судна, руб. | 1421235879 | переменные
Постоянные затраты в год, руб. | 199942039.2 | АУП и ИТР, маркетинг
Себестоимость серийного судна при темпе одно в год, руб. | 1621177918
Цена серийного судна без НДС, руб. | 1864354605 | с рентабельностью головного
Маржинальный доход с судна, руб. | 443118726.9
Точка безубыточности, судов в год | 0.45 | производство прибыльно с одного судна в год

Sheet: Окупаемость
Денежный поток программы: головное и серийные суда, руб.
Год | НИОКР | Капзатраты | Затраты на постройку | Выручка без НДС | Денежный поток | Коэф. дисконт. | Дисконтированный поток | Накопленный поток | Накопленный дисконт. | Окуп. | Окуп. диск.
2026 | 8846042.088 | 0 | 0 | 0 | -8846042.088 | 1.000 | -8846042.088 | -8846042.088 | -8846042.088
2027 | 43562825.71 | 22070000 | 740853752.4 | 0 | -806486578.2 | 0.870 | -701292676.7 | -815332620.2 | -710138718.7
2028 | 0 | 0 | 839666201.8 | 0 | -839666201.8 | 0.756 | -634908281.1 | -1654998822 | -1345047000
2029 | 0 | 0 | 640308457.6 | 0 | -640308457.6 | 0.658 | -421013204.6 | -2295307280 | -1766060204
2030 | 0 | 0 | 0 | 2553952674 | 2553952674 | 0.572 | 1460230730 | 258645394 | -305829474.3 | 2030
2031 | 0 | 0 | 1821555508 | 2094788835 | 273233326.3 | 0.497 | 135845253.1 | 531878720.2 | -169984221.2
2032 | 0 | 0 | 1930848839 | 2220476165 | 289627325.8 | 0.432 | 125213885.5 | 821506046.1 | -44770335.67
2033 | 0 | 0 | 2046699769 | 2353704735 | 307004965.4 | 0.376 | 115414537.9 | 1128511011 | 70644202.25 |  | 2033
2034 | 0 | 0 | 2169501755 | 2494927019 | 325425263.3 | 0.327 | 106382095.8 | 1453936275 | 177026298.1
2035 | 0 | 0 | 2299671861 | 2644622640 | 344950779.1 | 0.284 | 98056540.5 | 1798887054 | 275082838.6
NPV |  |  |  |  | 275082838.6
Инвестиции до первой выручки, дисконтированные |  |  |  |  | 1766060204
PI |  |  |  |  | 1.16
IRR |  |  |  |  | 20.8%
Срок окупаемости, лет от 2026 |  |  |  |  | 4
Дисконтированный срок окупаемости, лет от 2026 |  |  |  |  | 7

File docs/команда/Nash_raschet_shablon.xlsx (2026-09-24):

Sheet: Себестоимость проекта
Наименование статей калькуляции | Предложено организацией-поставщиком (подрядчиком, исполнителем) |  |  |  |  | Примечание
 | Всего | в том числе:
 |  | затраты за 2026 год | затраты за 2027 год | Затраты за 2028 год | Затраты за 2029 год
Материальные затраты - всего: | 793531404.35 | 0.00 | 793531404.35 | 0.00 | 0.00
в том числе:
приобретение сырья, материалов и вспомогательных материалов | 221923362.18 |  | 221923362.18 | 0.00
приобретение комплектующих изделий | 345880000.00 | 0.00 | 345880000.00 | 0.00
транспортно-заготовительные затраты (приняты на уровне % ТЗР, принятого в АО "АВ" | 225728042.18 |  | 225728042.18 | 0.00
Затраты на оплату труда - всего: | 813282857.48 | 0.00 | 66272626.83 | 528552231.37 | 218457999.27
в том числе:
основная заработная плата | 717431663.56 |  | 58461924.39 | 466258575.53 | 192711163.64
дополнительная заработная плата | 95851193.92 |  | 7810702.45 | 62293655.84 | 25746835.63
Страховые взносы на обязательное социальное страхование | 266756777.25 |  | 21737421.60 | 173365131.89 | 71654223.76
Общепроизводственные затраты | 0.00 |  | 0.00 | 0.00
Общехозяйственные затраты | 0.00 |  | 0.00 | 0.00
Прочие прямые затраты
Производственная себестоимость (сумма строк 0100, 0200, 0300, 0400, 0500 – 1200) | 1583458816.05 |  | 881541452.79 | 701917363.27
Коммерческие (внепроизводственные) затраты
Себестоимость продукции (сумма строк 1300, 1400, 1500, 1600) | 1583458816.05 | 0.00 | 881541452.79 | 701917363.27
в том числе:
привнесенные затраты | 0.00 |  |  | 0.00
собственные затраты | 0.00 |  | 0.00 | 0.00
Прибыль |  | Х | Х | Х
Цена продукции (без НДС) (сумма строк 1700, 1800) | 1583458816.05 | Х | Х | Х
Трудоемкость (нормо-часы) | 611468.55 |  | 53834.18 | 390644.43 | 166989.94

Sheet: Материалы
Расшифровка затрат на на приобретение сырья, материалов и вспомогательных материалов
Наименование материала | Единица измерения | Количество | Цена за единицу, без НДС | Сумма | Поставщик | Ссылка
Лист горячекатаный судостр 10х1600х6000, марка РС B | т | 660.00 | 60360.66 | 39838032.79 | АО "Металлсервис" | https://mc.ru/metalloprokat/stal_listovaya_g_k_sudostroitelnaya
Лист стальной 24х2000х6000 мм D36 ГОСТ Р 52927-2015 | т | 55.00 | 38812.76 | 2134702.02 | Торговая площадка "Пульс цен" | https://ekb.pulscen.ru/products/list_stalnoy_24kh2000kh6000_mm_d36_gost_r_52927_2015_303060267
Лист горячекатаный низколегир 6х1500х6000, марка 09Г2С-15 | т | 253.00 | 61214.33 | 15487224.95 | АО "Металлсервис" | Металлсервис: Лист 09Г2С (https://mc.ru/metalloprokat/stal_listovaya_g_k/mark/09g2s)
Швеллер низколегированный 12 П, длина 12 м, марка 09Г2С-15 | т | 234.00 | 96999.57 | 22697900.26 | АО "Металлсервис" | https://mc.ru/metalloprokat/shveller_nizkolegirovannyy_12_p_razmer_12_marka_09g2s-15_dlina_12000
Алюминиевый лист АМг5М РМРС 6х1500х4000 | кг | 130000.00 | 730.10 | 94913000.00 | ООО "Невская Алюминиевая Компания" | СПбАлюм: лист АМг5 (https://spbalum.ru/metal/alyuminievyj-list/alyuminievyj-list-amg5)
Тавр алюминиевый АМг5 20х20х2 ГОСТ 13622-91 | т | 23.00 | 255291.08 | 5871694.89 | "Металл-союз" | https://metsklad.ru/tavr-alyuminievyij/tavr-alyuminievyij-amg5-20x20x2-gost-13622-91/
Алюминиевый уголок АМг5 50х30х3,0х6000 уголок 410944 | т | 4.80 | 1379672.13 | 6622426.23 | ПКФ "Металл СВ" | https://www.sv-metal.ru/catalog/alluminiy/alyuminievyy-ugolok/amg5-50h30h3-0-l-6000-410944/
Алюминиевый уголок АМГ5 40х25х4 | т | 3.20 | 352247.54 | 1127192.13 | Компания Мост | https://moststal.ru/magazin/alyuminievyij-ugolok-amg5-40x25x4
Труба бесшовная (DN40–DN125), Ст20/09Г2С, ГОСТ 8732 | т | 75.40 | 135430.16 | 10211434.36 | ООО " МК "Буран" | https://spb.buranmetall.ru/truba-besshovnaya-09g2s/40x9?ysclid=muel5e80ub913359280
Труба бесшовная (DN20–DN80), 12Х18Н10Т (316L) | кг | 38.10 | 691.34 | 26340.22 | ООО ТК ИноксМаркет | InoxMarket: 12Х18Н10Т (https://www.inoxmarket.ru/truba_nerzhaveyushaya-c8/truba_12h18n10t-c52/)
Труба ПНД/ПП (DN50–DN225), судовая негорючая | м | 8.90 | 174.75 | 1555.31 | Компания Энерго Пайп | https://energo-pipe.ru/
Судовая арматура, фланцы, клапаны (PTFE для метанола) | шт. | 50.00 | 10833.38 | 541669.18 | ООО "ТД Ватервальве" | https://shop-watervalve.ru/59137/
Кабель силовой, контрольный, огнестойкий, слаботочный | м | 55.00 | 42.53 | 2339.38 | ООО "СнапКабель" | https://snabcable.ru/about_us/
Кабельные трассы (лотки ДКС), сальники, проходки | м | 25.00 | 401.97 | 10049.32 | АО "ДКС" | https://dkc-msk.ru/products/lotok-perforirovannyy-100kh50-l3000-35262/
Грунт эпоксидный + Foul Release (силиконовый, пресная вода) | шт. | 1700.00 | 832.90 | 1415935.57 | ГК ДЖИФЛЕКС | https://spb.gflex.ru/catalog/gruntovki/3276/?ysclid=muenx18ulq726592891
Грунт + Полиуретановая эмаль (UV-стойкая, КМ1/КМ2) | кг | 8800.00 | 2388.85 | 21021865.57 | Магазин красок "Колор" | https://color1.ru/antikorrozionnaya-poliuretanova-grunt-emal-indosingl-pu-tsvet-ral-9017-v-komplekte-s-otverditelem-1kg-0-25l
Итого затрат на материалы |  |  |  | 221923362.18

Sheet: ПКИ
Наименование ПКИ | Единица измерения | Количество | Цена за единицу, без НДС | Поставщик | Примечание
Обурудование для дизель- электрического пропульсивного комплекса | шт. | 1 | 67580000.00 | Weichai Power Co., Ltd. (Marine Division) | См. ТКП №1 в приложении
Гребные колёса и сопутствующее оборудование для судна | шт. | 1 | 13500000.00 | ООО «Плато-Инжиниринг» | См. ТКП №2 в приложении
Оборудование и арматура общесудовых систем и ситем СЭУ | шт. | 1 | 36800000.00 | ООО «Промтехнологии» | См. ТКП №3 в приложении
Система вентиляции и кондиционирования воздуха, ООО ХХР | шт. | 1 | 228000000.00 | ООО "ХХР" | См. ТКП №4 в приложении
Итого затраты на ПКИ |  |  | 345880000.00

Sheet: Расчёт трудоемкости
Расчет общей трудоёмкости ОПР, необходимой для работы на заказе
Этап работ согласно дорожной карте | Расчёт общей трудоёмкости |  |  | Распределение по годам, н/ч
 | Вид работ | Общая трудоемкость (чел/час) | Общая трудоемкость (н/час) | 2027 | 2028 | 2029
10.1. Корпусообработка, изготовление деталей | Обработка деталей корпуса | 33750.00 | 35437.50 | 10839.71 | 24597.79 | -
10.2. Сборка и сварка секций и блоков | Предварительная сборка конструкций | 81397.00 | 85466.85 | 26142.80 | 59324.05 | -
10.3. Изготовление изделий МСЧ | Изготовление изделий МСЧ | 73456.00 | 77128.80 | 16851.67 | 60277.13 | -
10.4.1. Формирование корпуса на стапеле | Формирование корпуса | 94632.00 | 99363.60 | - | 99363.60 | -
10.4.2. Монтаж механизмов | Механомонтажные работы | 41691.00 | 43775.55 | - | 43775.55 | -
10.4.3. Монтаж трубопроводов | Трубомонтажные работы | 46985.00 | 49334.25 | - | 49334.25 | -
11. Выполнение работ на достроечной набережной | Достроечные работы | 107867.00 | 113260.35 | - | 36203.45 | 77056.90
 | Электромонтажные работы | 52941.00 | 55588.05 | - | 17768.61 | 37819.44
12,14 Испытание кораблей | Испытания судна | 49632.00 | 52113.60 | - | - | 52113.60
Итого |  | 582351.00 | 611468.55 | 53834.18 | 390644.43 | 166989.94

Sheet: ФОТ_ОПР_расчёт
Фонд оплаты труда основных производственных рабочих
Вид работ | Трудоемкость, заработная плата, косвенные расходы за 2027-2029 гг.
 | Общая трудоемкость (н/час) | стоимость 1 н/час, руб.коп. | Основная заработная плата, руб.коп. | Дополнительная заработная плата |  | Отчисления на социальное страхование |  | ОПР |  | ОХР
 |  |  |  | % | Сумма (руб.коп.) | % | Сумма (руб.коп.) | % | Сумма (руб.коп.) | % | Сумма (руб.коп.)
2027 год
Обработка деталей корпуса | 10839.71 | 1127.65 | 12223346.41 | 13.36% | 1633078.67 | 32.80% | 4544907.43
Предварительная сборка конструкций | 26142.80 | 1127.65 | 29479801.63 | 13.36% | 3938596.98 | 32.80% | 10961234.74
Изготовление изделий МСЧ | 16851.67 | 994.49 | 16758776.35 | 13.36% | 2239026.80 | 32.80% | 6231279.43
Итого за 2027 год | 53834.18 |  | 58461924.39 |  | 7810702.45 |  | 21737421.60 |  | 0.00 |  | 0.00
2028 год
Обработка деталей корпуса | 24597.79 | 1204.84 | 29636358.26 | 13.36% | 3959513.45 | 32.80% | 11019445.92
Предварительная сборка конструкций | 59324.05 | 1204.84 | 71475884.58 | 13.36% | 9549409.68 | 32.80% | 26576296.52
Изготовление изделий МСЧ | 60277.13 | 1062.57 | 64048389.74 | 13.36% | 8557072.31 | 32.80% | 23814591.55
Формирование корпуса | 99363.60 | 1204.84 | 119717065.94 | 13.36% | 15994587.76 | 32.80% | 44513422.41
Механомонтажные работы | 43775.55 | 1323.92 | 57955271.44 | 13.36% | 7743011.97 | 32.80% | 21549036.96
Трубомонтажные работы | 49334.25 | 1323.92 | 65314538.59 | 13.36% | 8726233.90 | 32.80% | 24285373.38
Достроечные работы | 36203.45 | 1049.95 | 38011911.89 | 13.36% | 5078514.54 | 32.80% | 14133659.87
Электромонтажные работы | 17768.61 | 1131.16 | 20099155.10 | 13.36% | 2685312.22 | 32.80% | 7473305.28
Итого за 2028 год | 390644.43 |  | 466258575.53 |  | 62293655.84 |  | 173365131.89 |  | 0.00 |  | 0.00
2029 год
Достроечные работы | 77056.90 | 1137.64 | 87663393.15 | 13.36% | 11712113.25 | 32.80% | 32595166.10
Электромонтажные работы | 37819.44 | 1209.51 | 45742975.75 | 13.36% | 6111409.72 | 32.80% | 17008238.43
Испытания судна | 52113.60 | 1137.99 | 59304794.75 | 13.36% | 7923312.66 | 32.80% | 22050819.23
Итого за 2029 год | 166989.94 |  | 192711163.64 |  | 25746835.63 |  | 71654223.76 |  | 0.00 |  | 0.00
ВСЕГО | 611468.55 |  | 717431663.56 |  | 95851193.92 |  | 266756777.25 |  | 0.00 |  | 0.00

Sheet: ДЗП_расчёт
Структура ДЗП
Наименование | Продолжительность, дни
Ежегодный основной и дополнительный отпуск, предусмотренный законодательством Российской Федерации (без денежной компенсации за неиспользованный отпуск) | 28
Временная нетрудоспособность (больничный лист) работника в соответствии с нормами законодательства РФ | 3 | В среднем, по данным исследований (вставить ссылку)
Время медицинского обследования, дней сдачи крови и ее компонентов и предоставленных в связи с этим дней отдыха | 2 | (в среднем в соответствии с ТК)
Итого | 33
База распределения - количество рабочих дней | 247.00
% ДЗП | 13.36%

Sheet: Соц_страх_расчёт
Структура отчислений во внебюджетные фонды | Величина отчислений, % | Примечание
Обязательное пенсионное страхование | 0.22
Обязательное медицинское страхование | 0.051
Обязательное социальное страхование на случай временной нетрудоспособности и в связи с материнством | 0.029
От несчастных случаев на производстве и профзаболеваний | 0.028 | Согл. ОКВЭД
Итого | 0.328

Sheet: АУП_ИТР_расчёт
Наименование должности | Кол-во | База, руб. | Категория персонала | База, руб. | Премия, 10% | Итого основная ЗП | ДЗП | Отчисления во внебюджетные фонды | Итого затраты на оплату труда | Ссылка на вакансию
Зам. главного инженера | 1 | 130000.00 | АУП | 130000.00 | 13000.00 | 143000.00 | 19105.26 | 53170.53 | 215275.79 | https://spb.hh.ru/vacancy/136536917?query=заместитель+главного+инженера&hhtmFrom=vacancy_search_list
Ведущий конструктор | 4 | 170000.00 | ИТР | 680000.00 | 68000.00 | 748000.00 | 99935.22 | 278122.75 | 1126057.98 | https://spb.hh.ru/vacancy/137042333?query=ведущий+конструктор&hhtmFrom=vacancy_search_list
Ведущий технолог | 4 | 100000.00 | ИТР | 400000.00 | 40000.00 | 440000.00 | 58785.43 | 163601.62 | 662387.04 | https://spb.hh.ru/vacancy/137049104?query=ведущий+технолог&hhtmFrom=vacancy_search_list
Ведущий специалист технического контроля | 3 | 150000.00 | ИТР | 450000.00 | 45000.00 | 495000.00 | 66133.60 | 184051.82 | 745185.43 | https://spb.hh.ru/vacancy/135598070?query=ведущий+специалист+технического+контроля&hhtmFrom=vacancy_search_list
Ведущий экономист | 2 | 120000.00 | АУП | 240000.00 | 24000.00 | 264000.00 | 35271.26 | 98160.97 | 397432.23 | https://spb.hh.ru/vacancy/136537115?query=ведущий+экономист&hhtmFrom=vacancy_search_list
Ведущий инженер-технолог | 4 | 150000.00 | ИТР | 600000.00 | 60000.00 | 660000.00 | 88178.14 | 245402.43 | 993580.57 | https://spb.hh.ru/vacancy/137482925?query=ведущий+инженер-технолог&hhtmFrom=vacancy_search_list
Инженер - конструктор 1 кат. | 4 | 150000.00 | ИТР | 600000.00 | 60000.00 | 660000.00 | 88178.14 | 245402.43 | 993580.57 | https://spb.hh.ru/vacancy/136907155?query=инженер-конструктор+1+категории&hhtmFrom=vacancy_search_list
Технолог 1 кат. | 5 | 120000.00 | ИТР | 600000.00 | 60000.00 | 660000.00 | 88178.14 | 245402.43 | 993580.57 | https://spb.hh.ru/vacancy/137572170?query=технолог+1+категории&hhtmFrom=vacancy_search_list
Итого: | 27 | 1090000.00 |  | 3700000.00 |  | 4070000.00 | 543765.18 | 1513314.98 | 6127080.16
Начальник производства | 1 | 200000.00 | АУП | 200000.00 | 20000.00 | 220000.00 | 29392.71 | 81800.81 | 331193.52 | https://spb.hh.ru/vacancy/137711314?query=начальник+производства&hhtmFrom=vacancy_search_list
Начальник участка | 5 | 170000.00 | ИТР | 850000.00 | 85000.00 | 935000.00 | 124919.03 | 347653.44 | 1407572.47 | https://spb.hh.ru/vacancy/137569275?query=начальник+участка&hhtmFrom=vacancy_search_list
Старший мастер участка | 7 | 180000.00 | ИТР | 1260000.00 | 126000.00 | 1386000.00 | 185174.09 | 515345.10 | 2086519.19 | https://spb.hh.ru/vacancy/136540024?query=старший+мастер+участка&hhtmFrom=vacancy_search_list
Мастер участка | 7 | 130000.00 | ИТР | 910000.00 | 91000.00 | 1001000.00 | 133736.84 | 372193.68 | 1506930.53 | https://spb.hh.ru/vacancy/137655586?query=мастер+участка&hhtmFrom=vacancy_search_list
Специалист по охране труда | 2 | 120000.00 | ИТР | 240000.00 | 24000.00 | 264000.00 | 35271.26 | 98160.97 | 397432.23 | https://spb.hh.ru/vacancy/137697813?query=специалист+по+охране+труда&hhtmFrom=vacancy_search_list
Специалист по МТО | 2 | 150000.00 | ИТР | 300000.00 | 30000.00 | 330000.00 | 44089.07 | 122701.21 | 496790.28 | https://spb.hh.ru/vacancy/137355491?query=специалист+по+МТО&hhtmFrom=vacancy_search_list
Наладчик системы | 10 | 100000.00 | ИТР | 1000000.00 | 100000.00 | 1100000.00 | 146963.56 | 409004.05 | 1655967.61 | https://spb.hh.ru/vacancy/136953728?query=наладчик+системы&hhtmFrom=vacancy_search_list
Кладовщик | 7 | 75000.00 | ВПР | 525000.00 | 52500.00 | 577500.00 | 77155.87 | 214727.13 | 869383.00 | https://spb.hh.ru/vacancy/137709749?query=кладовщик+на+завод&hhtmFrom=vacancy_search_list
Специалист по связям с общественностью | 2 | 80000.00 | РСИС | 160000.00 | 16000.00 | 176000.00 | 23514.17 | 65440.65 | 264954.82 | https://spb.hh.ru/vacancy/132322232?query=специалист+по+связям+с+общественностью&hhtmFrom=vacancy_search_list
Строитель кораблей | 7 | 120000.00 | ИТР | 840000.00 | 84000.00 | 924000.00 | 123449.39 | 343563.40 | 1391012.79 | https://spb.hh.ru/search/vacancy?text=главный+строитель+кораблей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
Итого: | 50 | 1325000.00 |  | 6285000.00 |  | 6913500.00 | 923665.99 | 2570590.45 | 10407756.44
Всего затрат на АУП |  |  |  |  |  |  |  |  | 16534836.60

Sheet: Обязательное обучение
Обучающая организация | Тема обучения | стоимость обучения за 1 чел | Кол-во сотрудников | Итого:
АНО ДПО «Учебный центр «Перспектива» | Организация деятельности и эксплуатации электроустановок для производства испытаний (измерений)-электролабораторий | 4368.00 | 30 | 131040.00
АНО ДПО «Прикамский институт безопасности | Поверка и калибровка средств измерений теплотехнических величин (давления, расхода, температуры) 108 часов | 8320.00 | 15 | 124800.00
АНО ДПО «ДВИПРАЗ» | Поверка и калибровка средств геометрических измерений | 547.04 | 25 | 13676.00
ЧОУ ДПО "Учебный центр "Конфакт" | Повторная проверка знаний машиниста плавучего крана. | 2080.00 | 35 | 72800.00
ЧОУ ДПО "Морские системы" | Подготовка в соответствии с требованиями пунктов 1-4 Раздела А-VI/I кодекса ПДНВ | 7592.00 | 20 | 151840.00
ООО Многофункциональный Учебно-Информационный Центр "Меркурий" | Специалист по пожарной профилактике | 364.00 | 100 | 36400.00
ЧОУ ДПО "Спутник" | Техносферная безопасность. Охрана труда | 840.32 | 150 | 126048.00
ЧОУ ДПО "Морские системы" | Подготовка специалиста по спасательным шлюпкам и плотам и дежурным шлюпкам, не являющимся скоростными дежурными шлюпками, в соответствии с пунктами 1-4 раздела A-VI/2 Кодекса ПДНВ (Пункт 1.3 Правила VI/2 Конвенции ПДНВ) (первично) | 3120.00 | 30 | 93600.00
ИП Климчук В.А. | Обучение по охране труда | 391872.00 | общий договор | 391872.00
ИП Лысенко И.М. | Обучение по электробезопасности | 185318.82 | общий договор | 185318.82
АНО ДПО "ПРОФАТОМЭНЕРГО" | Обучение по радиационной безопасности | 318614.40 | общий договор | 318614.40
Итого затраты на обязательное обучение |  | 923036.58 |  | 1646009.22

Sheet: Маркетинг
Поставшик | Варианты рекламы | Стоимость руб./месяц | Источник
Метроплитен СПБ | Реклама на щитах 4×2 м | 124000.00 | Макет будет выполнен дизайнером отдела по связям с общественность АО "Адмиралтейские верфи" https://www.metro-spb.ru/reklama-na-stanciyah-metro/shchit-putevoj.htm?ysclid=mudu3rg6be486653059
АО "Адмиралтейские верфи" | Буклеты, раздаточная продукция | 3000.00 | Печать будет осуществляться в типографии предприятия из расчета 30 рублей за буклет А4, цветная печать с двух сторон, в количестве 100 штук. Буклеты будут раздаваться силами работников на профориетационных и других рекламных мероприятиях (Конференциях, Выставках и т.д.)
АО "Адмиралтейские верфи" | Реклама в социальных сетях | 0.00 | АО "Адмиралтейские верфи" ведут несколько социальных сетей на разных площадках: Телеграм, Макс, Вконтакте силами сотрудников предприятия
Итого затраты на маркетинг и продвижение за год |  | 1524000.00

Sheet: ОПР_Расчет
01.10 - Материалы
01.22 - Расходы на приобретение, изготовление и ремонт инструмента, инвентаря
01.23 - Расходы на ГСМ и топливо
01.25 - Расходы на сварочное оборудование, расходные и комплектующие материалы
01.27 - Прочие расходы обеспечивающие охрану труда (мыло, защитные средства и прочее)
01.29 - Расходы на мебель
01.30 - Расходы на МБП не производственного характера
02.11.в - Расходы на обеспечение цехов энергетическими услугами на технологические цели (вода)
02.11.г - Расходы на обеспечение цехов энергетическими услугами на технологические цели (газы)
02.11.с - Расходы на обеспечение цехов энергетическими услугами на технологические цели (стоки)
02.11.т - Расходы на обеспечение цехов энергетическими услугами на технологические цели (тепло)
02.11.э - Расходы на обеспечение цехов энергетическими услугами на технологические цели (электричество)
03.11 - Расходы на приобретение работ и услуг производственного характера, выполняемых сторонними организациями
03.12 - Расходы на ремонт оборудования, транспортных средств
03.15 - Расходы на обеспечение производства транспортными услугами
Расходы на оплату труда общепроизводственного персонала, занятого в обеспечении производства
Страховые взносы на зарплату общепроизводственного персонала
11.10 - Амортизация оборудования и транспортных средств
11.11 - Амортизация зданий, сооружений.
14.12 - Расходы на охрану труда
14.13 - Прочие расходы по договорам на выполнение работ по содержанию и эксплуатации зданий и сооружений
14.15 - Расходы на приобретение индив.средств защиты,спецодежды,спецобуви,ремонт и стирка спецодежды
14.16 – Обеспечение работников вредных производств молоком и другими равноценными продуктами
14.17 - Вывоз мусора,зарядка огнетушителей,дезинсекция, дератизация и пр.
14.22 - Информационные услуги (интернет, правовые базы и пр.) и программ.продукты
14.23 - Техническое обслуживание
14.24 - Страхование имущества
14.27 - Командировочные расходы
14.31 - Прочие налоги
14.32 - Расходы на противопожарную безопасность
14.33 - Медицинский осмотр работников организации
14.34 - Канцелярские расходы и расходы, связанные с типографскими и копировально-множительными работами
14.35 - Оргтехника расходные материалы и программное обеспечение
14.36 - Расходы на почтовые, телеграфные услуги и услуги связи
14.38 - Услуги, оказываемые подразделениями организации
14.39 - Экспертизы, поверки и прочее

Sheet: ОХР_Расчет
Оплата труда персоналу общехозяйственного назначения
Страховые взносы с оплаты труда персонала общехозяйственного назанчения
01.23 - Расходы на ГСМ и топливо
01.31 - Прочие материалы
01.32 - Расходы на спец. одежду и средства индивидуальной защиты
01.33 - Расходы на инструмент и прочие приспособления
01.34 - Расходы на оргтехнику, ремонт и содержание
11.12 - Амортизация ОС, НМА
17.10 - Аренда и лизинг
17.11в - Расходы на обеспечение общества энергетическими услугами (вода)
17.11с - Расходы на обеспечение общества энергетическими услугами (стоки)
17.11т - Расходы на обеспечение общества энергетическими услугами (тепло)
17.11э - Расходы на обеспечение общества энергетическими услугами (электричество)
17.12 - Расходы на содержание основных средств общехозяйственного назначения
17.13 - Расходы на ремонт зданий и сооружений
17.14 - Расходы по обеспечению безопасности и гражданской обороны общества
17.15 - Канцелярские расходы и расходы, связанные с типографскими и копировально-множительными работ
17.17 - Расходы на обеспечение служб общества транспортными услугами, содержание автопарка
17.19 - Информационные материалы (подписные издания и т.п.)
17.20 - Расходы на почтовые, телеграфные услуги и услуги связи
17.22 - Представительские расходы
17.23 - Поддержка и сопровождение программного обеспечения
17.24 - Оргтехника расходные материалы и программное обеспечение
17.25 - Расходы по обязательным видам страхования
17.26 - Расходы на обучение кадров и повышение квалификации (в том числе семинары)
17.27 - Расходы, связанные с совершенствованием технологии и организации производства
17.28 - Расходы на охрану труда
17.29 - Расходы на оплату консультационных, юридических услуг
17.30 - Расходы на оплату налогов и сборов
17.31 - Прочие расходы
17.34 - Лицензирование, сертификация
17.35 - Услуги типографии
17.37 - Медицинский осмотр работников организации
17.38 - Услуги, оказываемые подразделениями организации
17.39 - Пользование водными объектами
17.40 - Услуги сторонних организаций
17.41 - Техническое обслуживание
17.44 - Текущий ремонт оборудования и транспорта
17.46 - Испытания, содержание лабораторий
17.49 - Ремонт зданий и сооружений
17.51 - Транспортный налог
17.52 - Налог на имущество
17.53 - Земельный налог
17.55 - Экспертизы, поверки и прочее
17.58 - Дезинфекция, дезинсекция и дератизация
17.59 - Вывоз и утилизация мусора
17.64 - ТЗР общехозяйственные
17.65 - Затраты на подбор персонала
17.71 - Командировочные расходы
79… - Расходы отдельных подразделений вспомогательного производства, связанные с работами инженерно-технического обслуживания основного производства продукции, работ (услуг) АО "Адмиралтейские верфи"

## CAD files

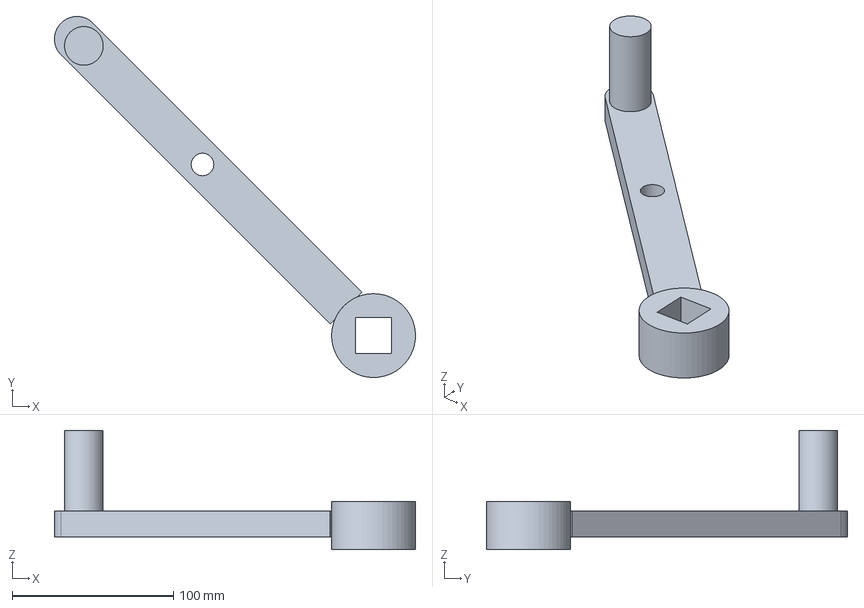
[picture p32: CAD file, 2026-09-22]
CAD/STEP/VG-2026_46_03_lever.step
223.8 x 223.8 x 74.0 mm

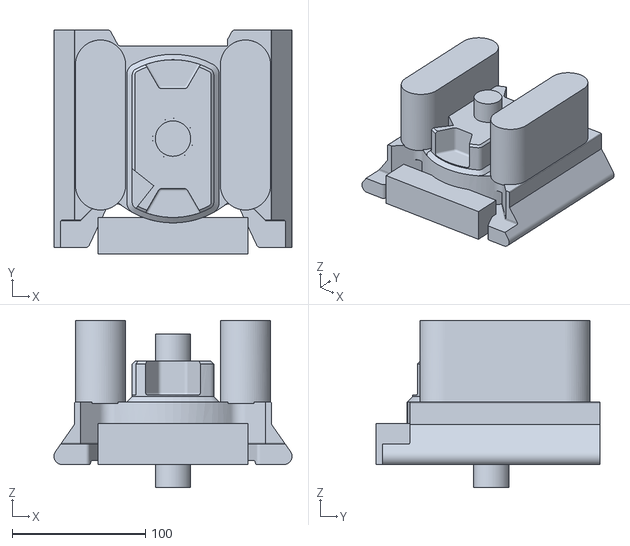
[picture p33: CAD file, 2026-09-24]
CAD/STL/VG-2026_46_01-MD_pattern.stl
178.5 x 168.3 x 125.5

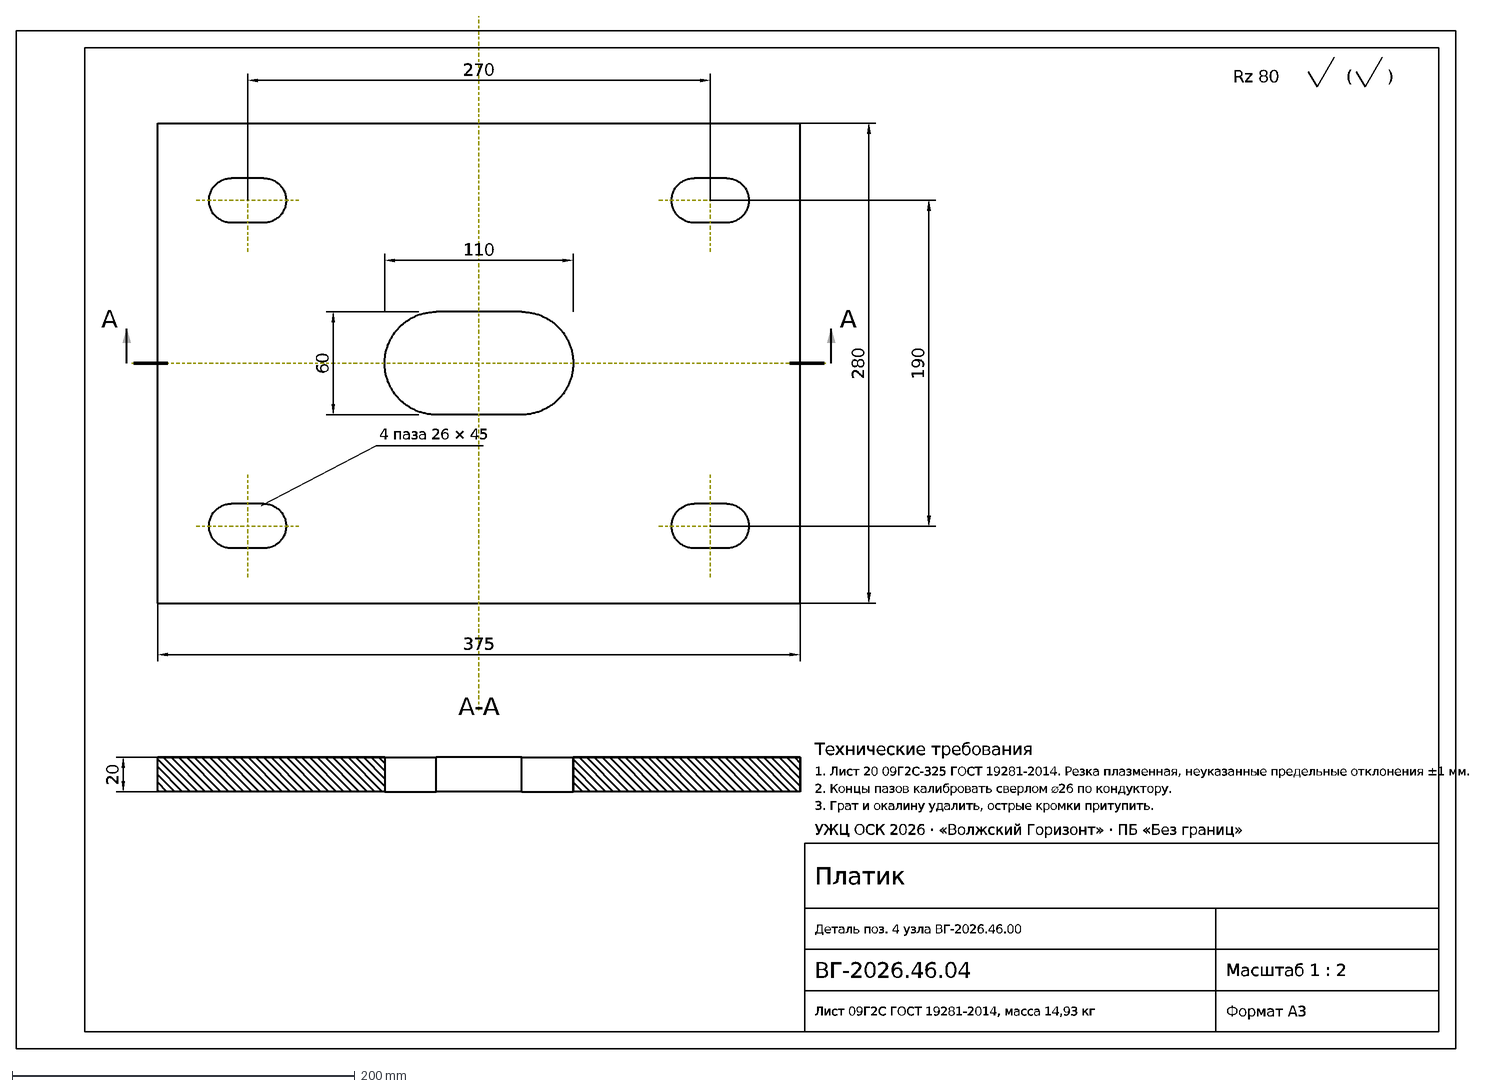
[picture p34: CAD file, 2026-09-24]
CAD/узел/ВГ-2026_46_04_платик.dxf
375
270
280
190
110
60
4 паза 26 × 45
А
А-А
20
Rz 80
(
)
Платик
Деталь поз. 4 узла ВГ-2026.46.00
ВГ-2026.46.04
Масштаб 1 : 2
Лист 09Г2С ГОСТ 19281-2014, масса 14,93 кг
Формат A3
УЖЦ ОСК 2026 · «Волжский Горизонт» · ПБ «Без границ»
1. Лист 20 09Г2С-325 ГОСТ 19281-2014. Резка плазменная, неуказанные предельные отклонения ±1 мм.
2. Концы пазов калибровать сверлом ⌀26 по кондуктору.
3. Грат и окалину удалить, острые кромки притупить.
Технические требования

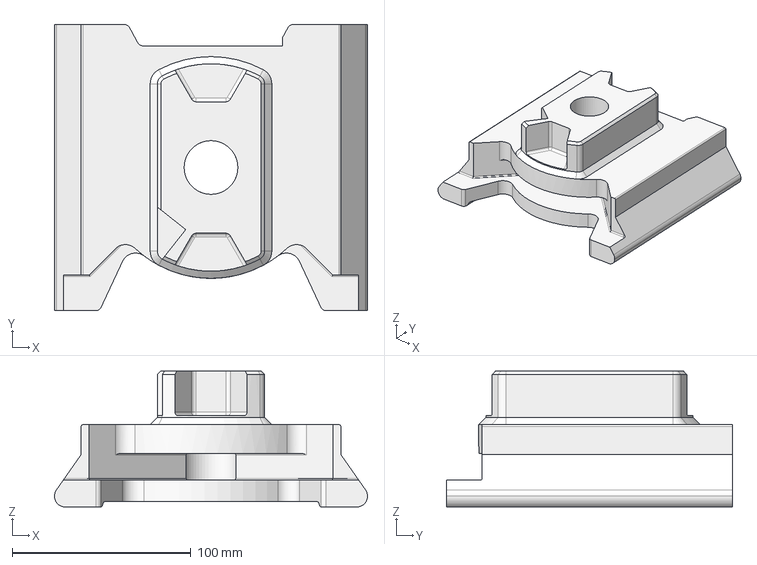
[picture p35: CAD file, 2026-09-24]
docs/команда/правки 23.09.26/Korpus_tvistloka_model_uzel.stp
175.0 x 160.0 x 76.0 mm

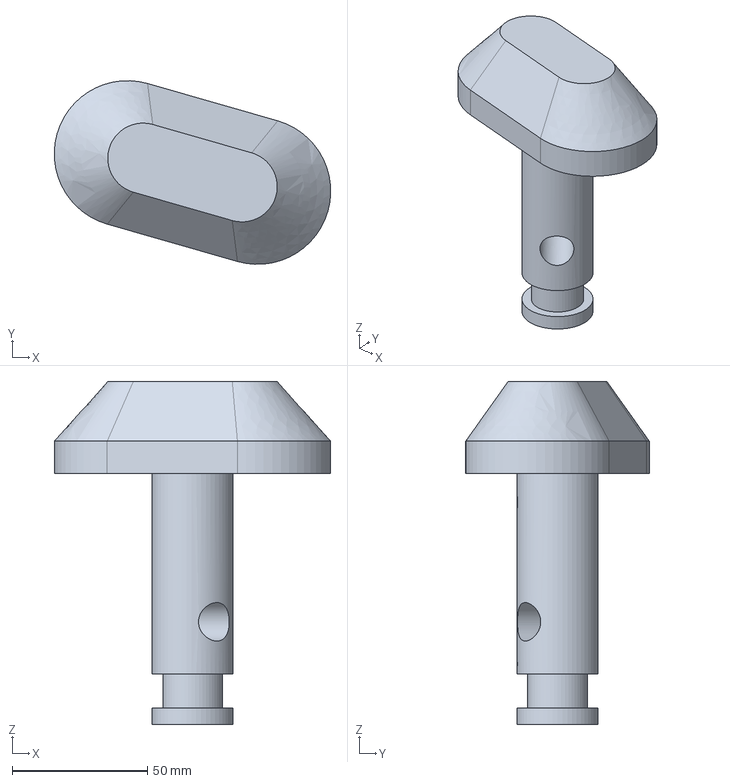
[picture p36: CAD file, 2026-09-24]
Сдача/3. Конструкторская документация/3D модель/ВГ-2026.46.03 элемент запирающий.step
102.0 x 67.7 x 126.6 mm

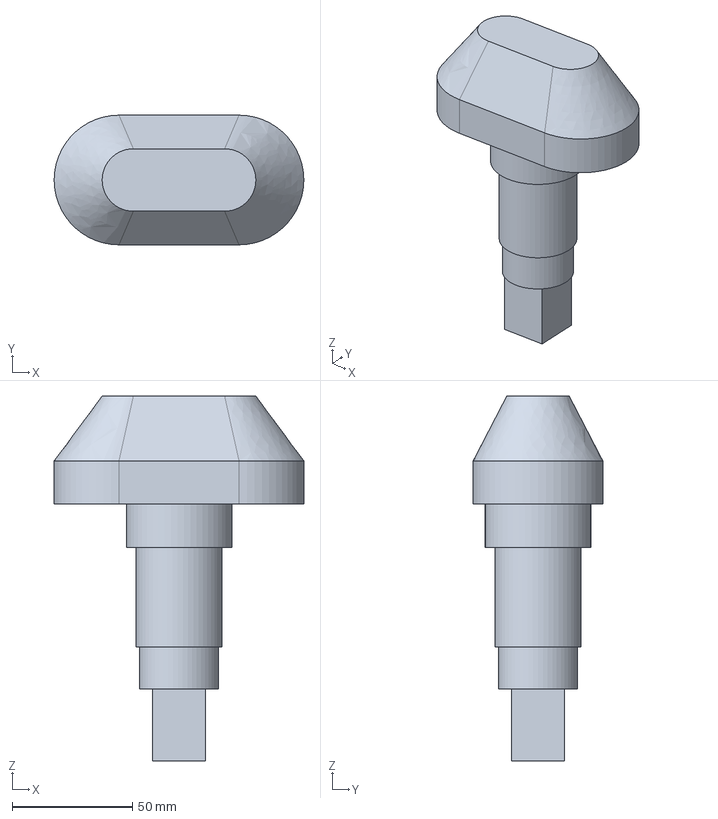
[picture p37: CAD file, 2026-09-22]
CAD/STEP/VG-2026_46_02_lock.step
104.0 x 54.0 x 152.0 mm

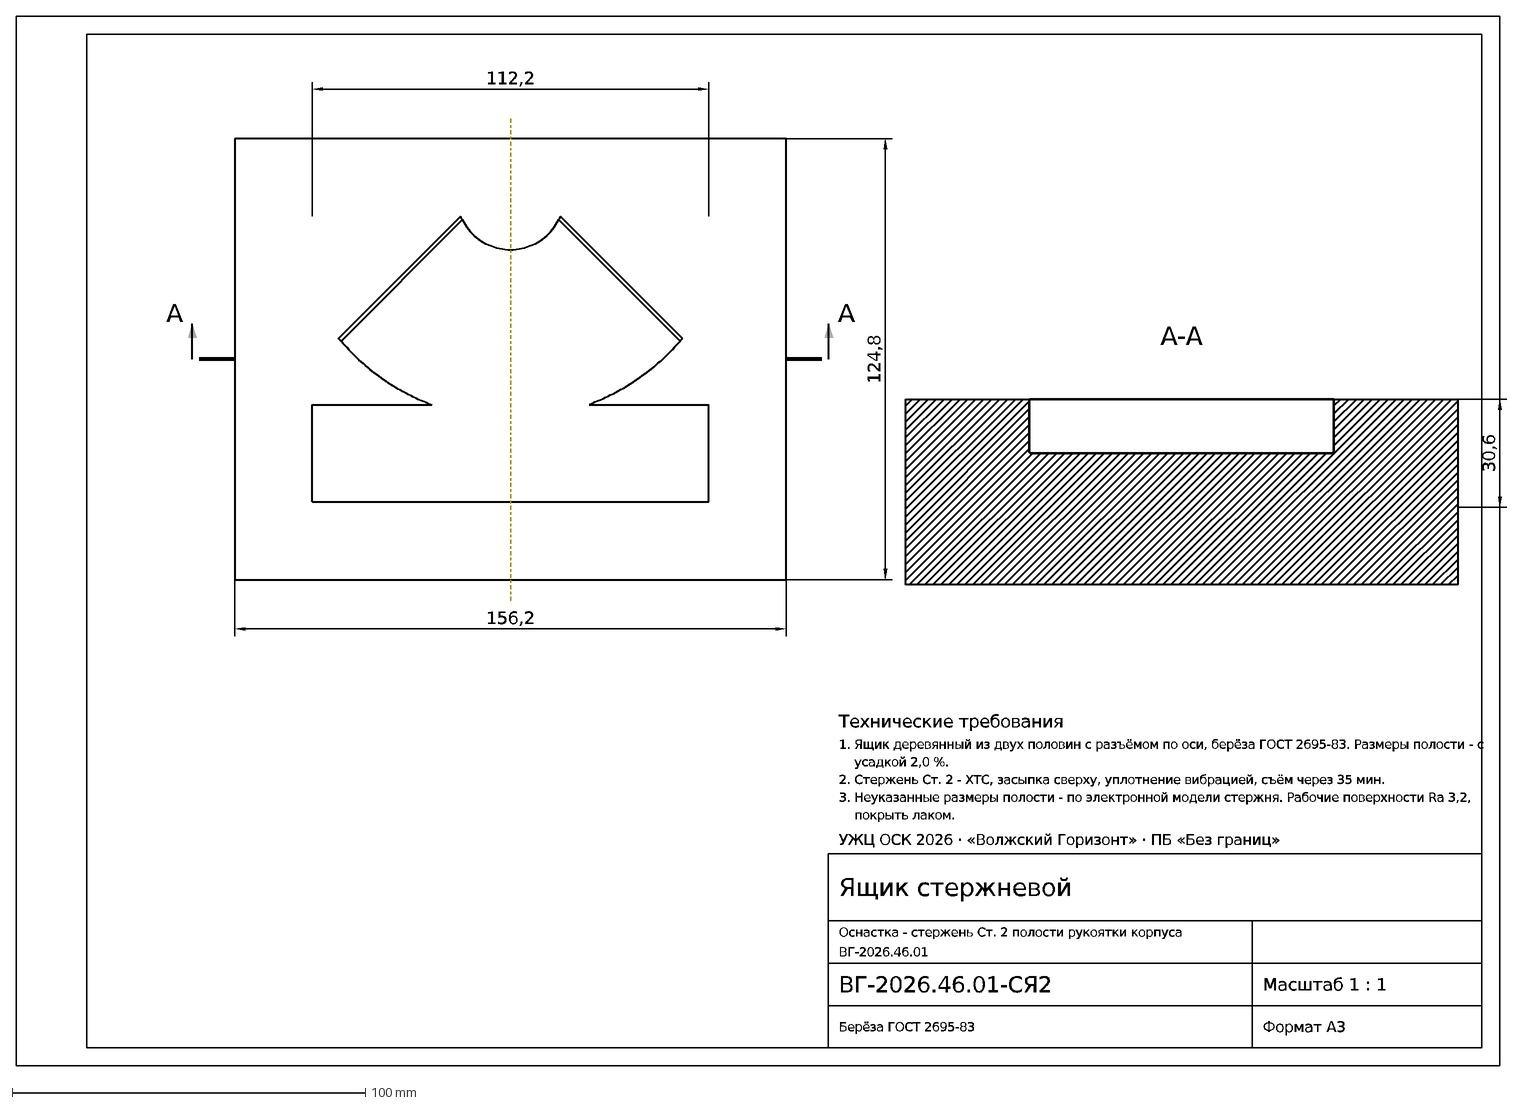
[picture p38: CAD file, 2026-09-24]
CAD/узел/ВГ-2026_46_01-СЯ2_ящик_стержневой.dxf
156,2
124,8
112,2
А
30,6
А-А
Ящик стержневой
Оснастка - стержень Ст. 2 полости рукоятки корпуса
ВГ-2026.46.01
ВГ-2026.46.01-СЯ2
Масштаб 1 : 1
Берёза ГОСТ 2695-83
Формат A3
УЖЦ ОСК 2026 · «Волжский Горизонт» · ПБ «Без границ»
1. Ящик деревянный из двух половин с разъёмом по оси, берёза ГОСТ 2695-83. Размеры полости - с
усадкой 2,0 %.
2. Стержень Ст. 2 - ХТС, засыпка сверху, уплотнение вибрацией, съём через 35 мин.
3. Неуказанные размеры полости - по электронной модели стержня. Рабочие поверхности Ra 3,2,
покрыть лаком.
Технические требования

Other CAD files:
CAD/ВГ-2026_ОР-06_поперечные_сечения.dxf
CAD/модули/ВГ-2026_МР-03.dxf
CAD/расчёты/ВГ-2026_РТ-08_мидель_шпангоут.dxf
Сдача/2. Дизайн-проект/DWG/ВГ-2026 РТ-03 строевая и нагрузка.dwg
Сдача/3. Конструкторская документация/DWG/ВГ-2026.46.00 СБ.dwg
Сдача/4. Технология и организация производства/3D оснастки/ВГ-2026.46.01-МД модель.step
Сдача/4. Технология и организация производства/DWG/ВГ-2026.46.01-СЯ1 ящик стержневой.dwg
CAD/STL/VG-2026_46_03_lock.stl
CAD/ВГ-2026_ОР-04_трюм_и_второе_дно.dxf
CAD/модули/ВГ-2026_МР-01.dxf
CAD/расчёты/ВГ-2026_РТ-09_схема_набора.dxf
CAD/STL/VG-2026_46_00_twistlock.stl
CAD/STL/VG-2026_46_01_body.stl
CAD/STL/VG-2026_46_01_casting.stl
CAD/STL/VG-2026_46_01_core.stl
CAD/STL/VG-2026_46_02_lock.stl
CAD/STL/VG-2026_46_02_rod.stl
CAD/STL/VG-2026_46_03_lever.stl
CAD/STL/VG-2026_46_04_plate.stl
CAD/STL/VG-2026_46_05_washer.stl
CAD/ВГ-2026_ОР-01_главная_палуба.dxf
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

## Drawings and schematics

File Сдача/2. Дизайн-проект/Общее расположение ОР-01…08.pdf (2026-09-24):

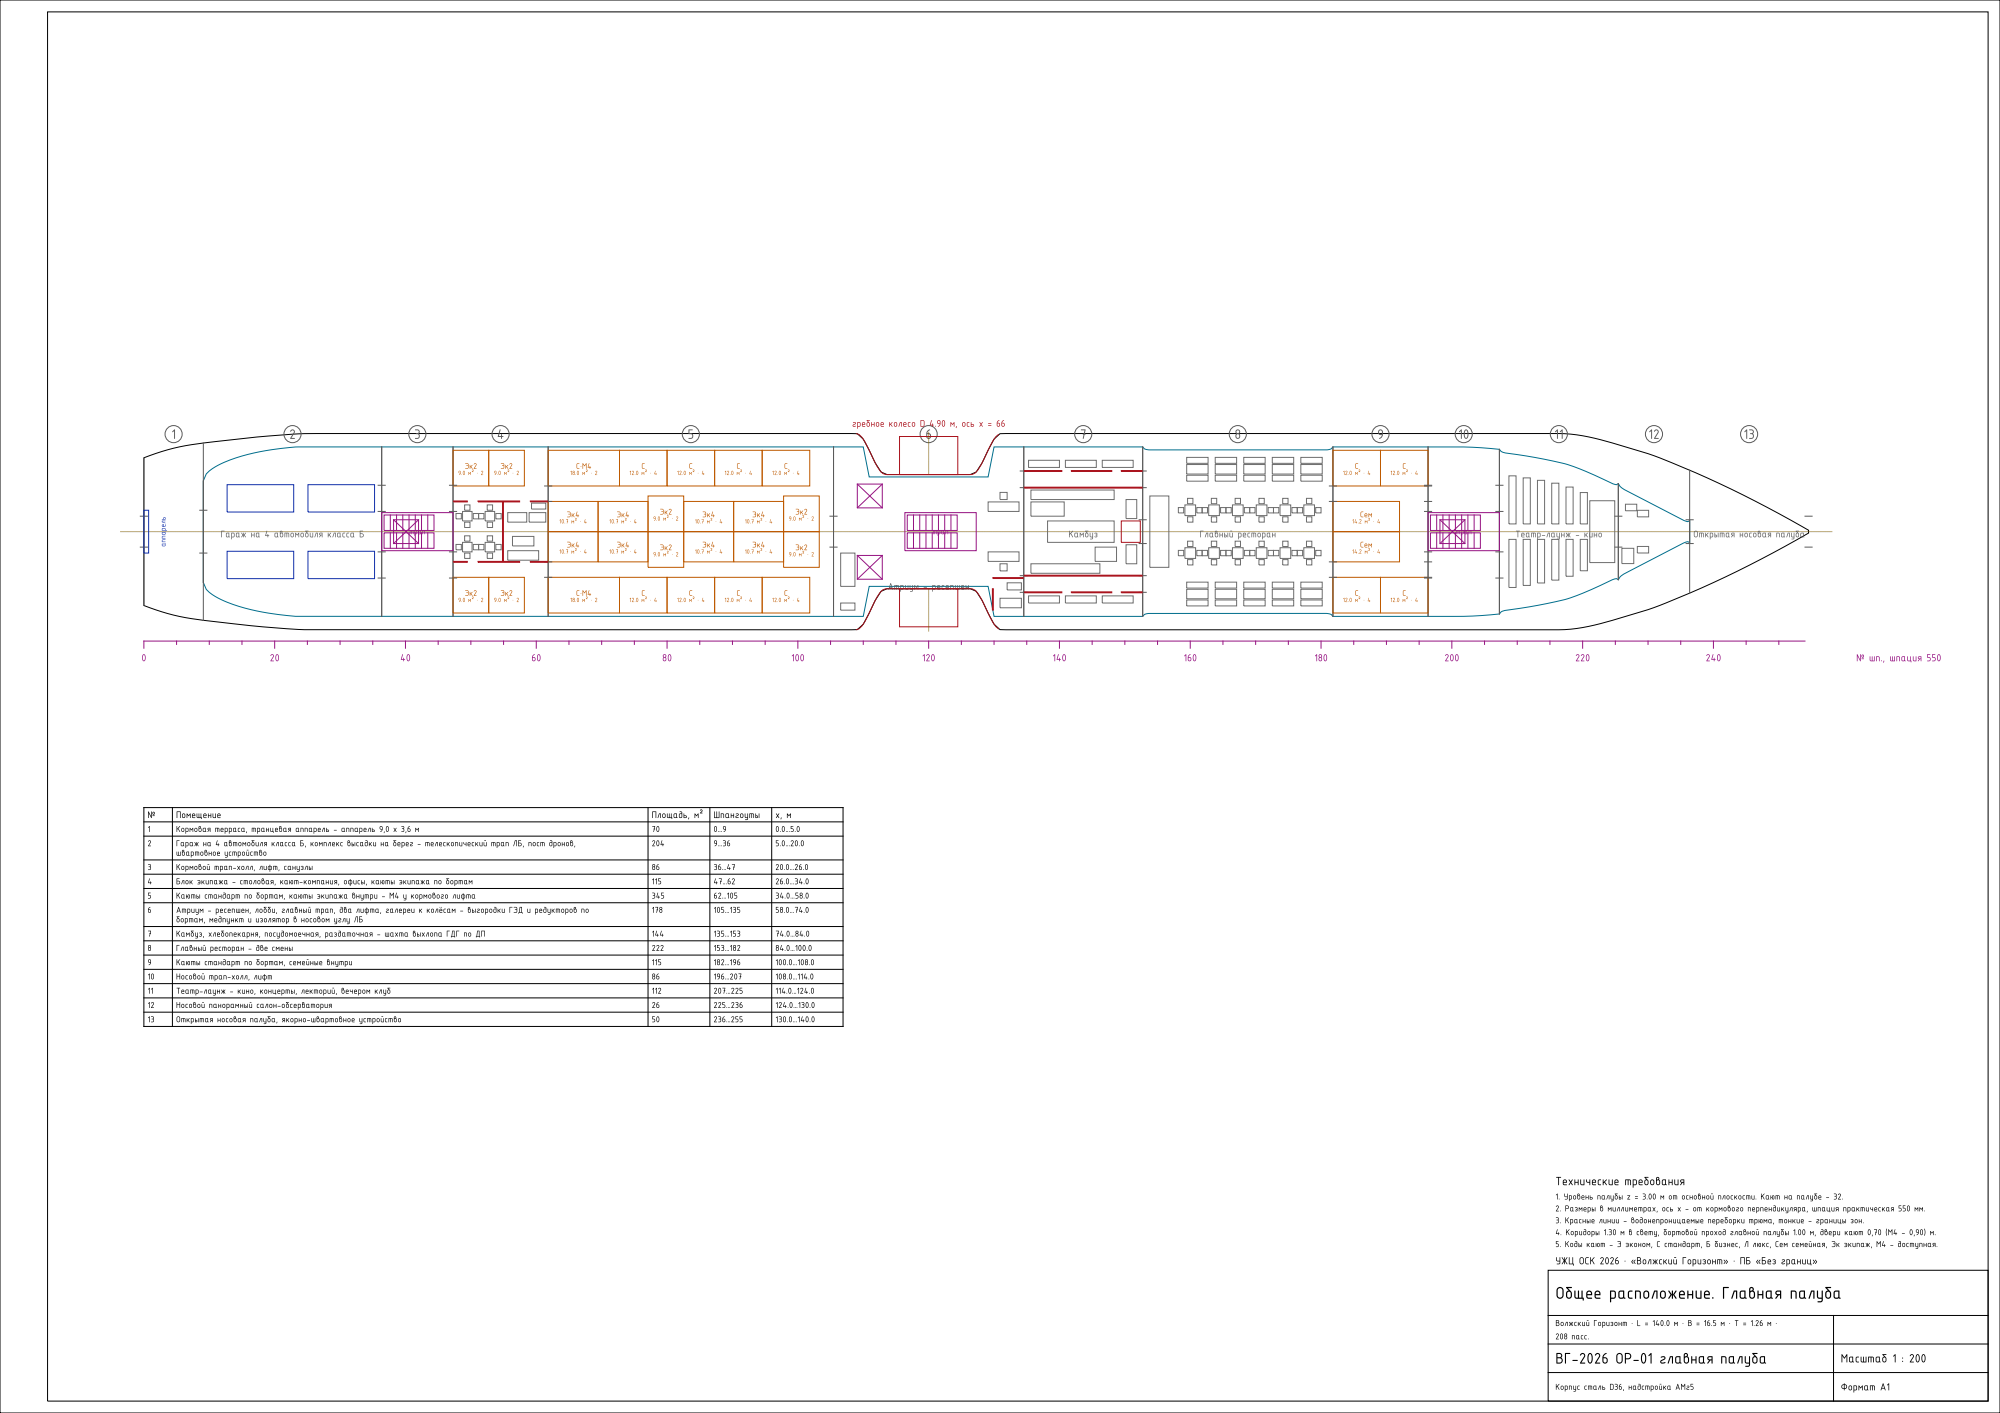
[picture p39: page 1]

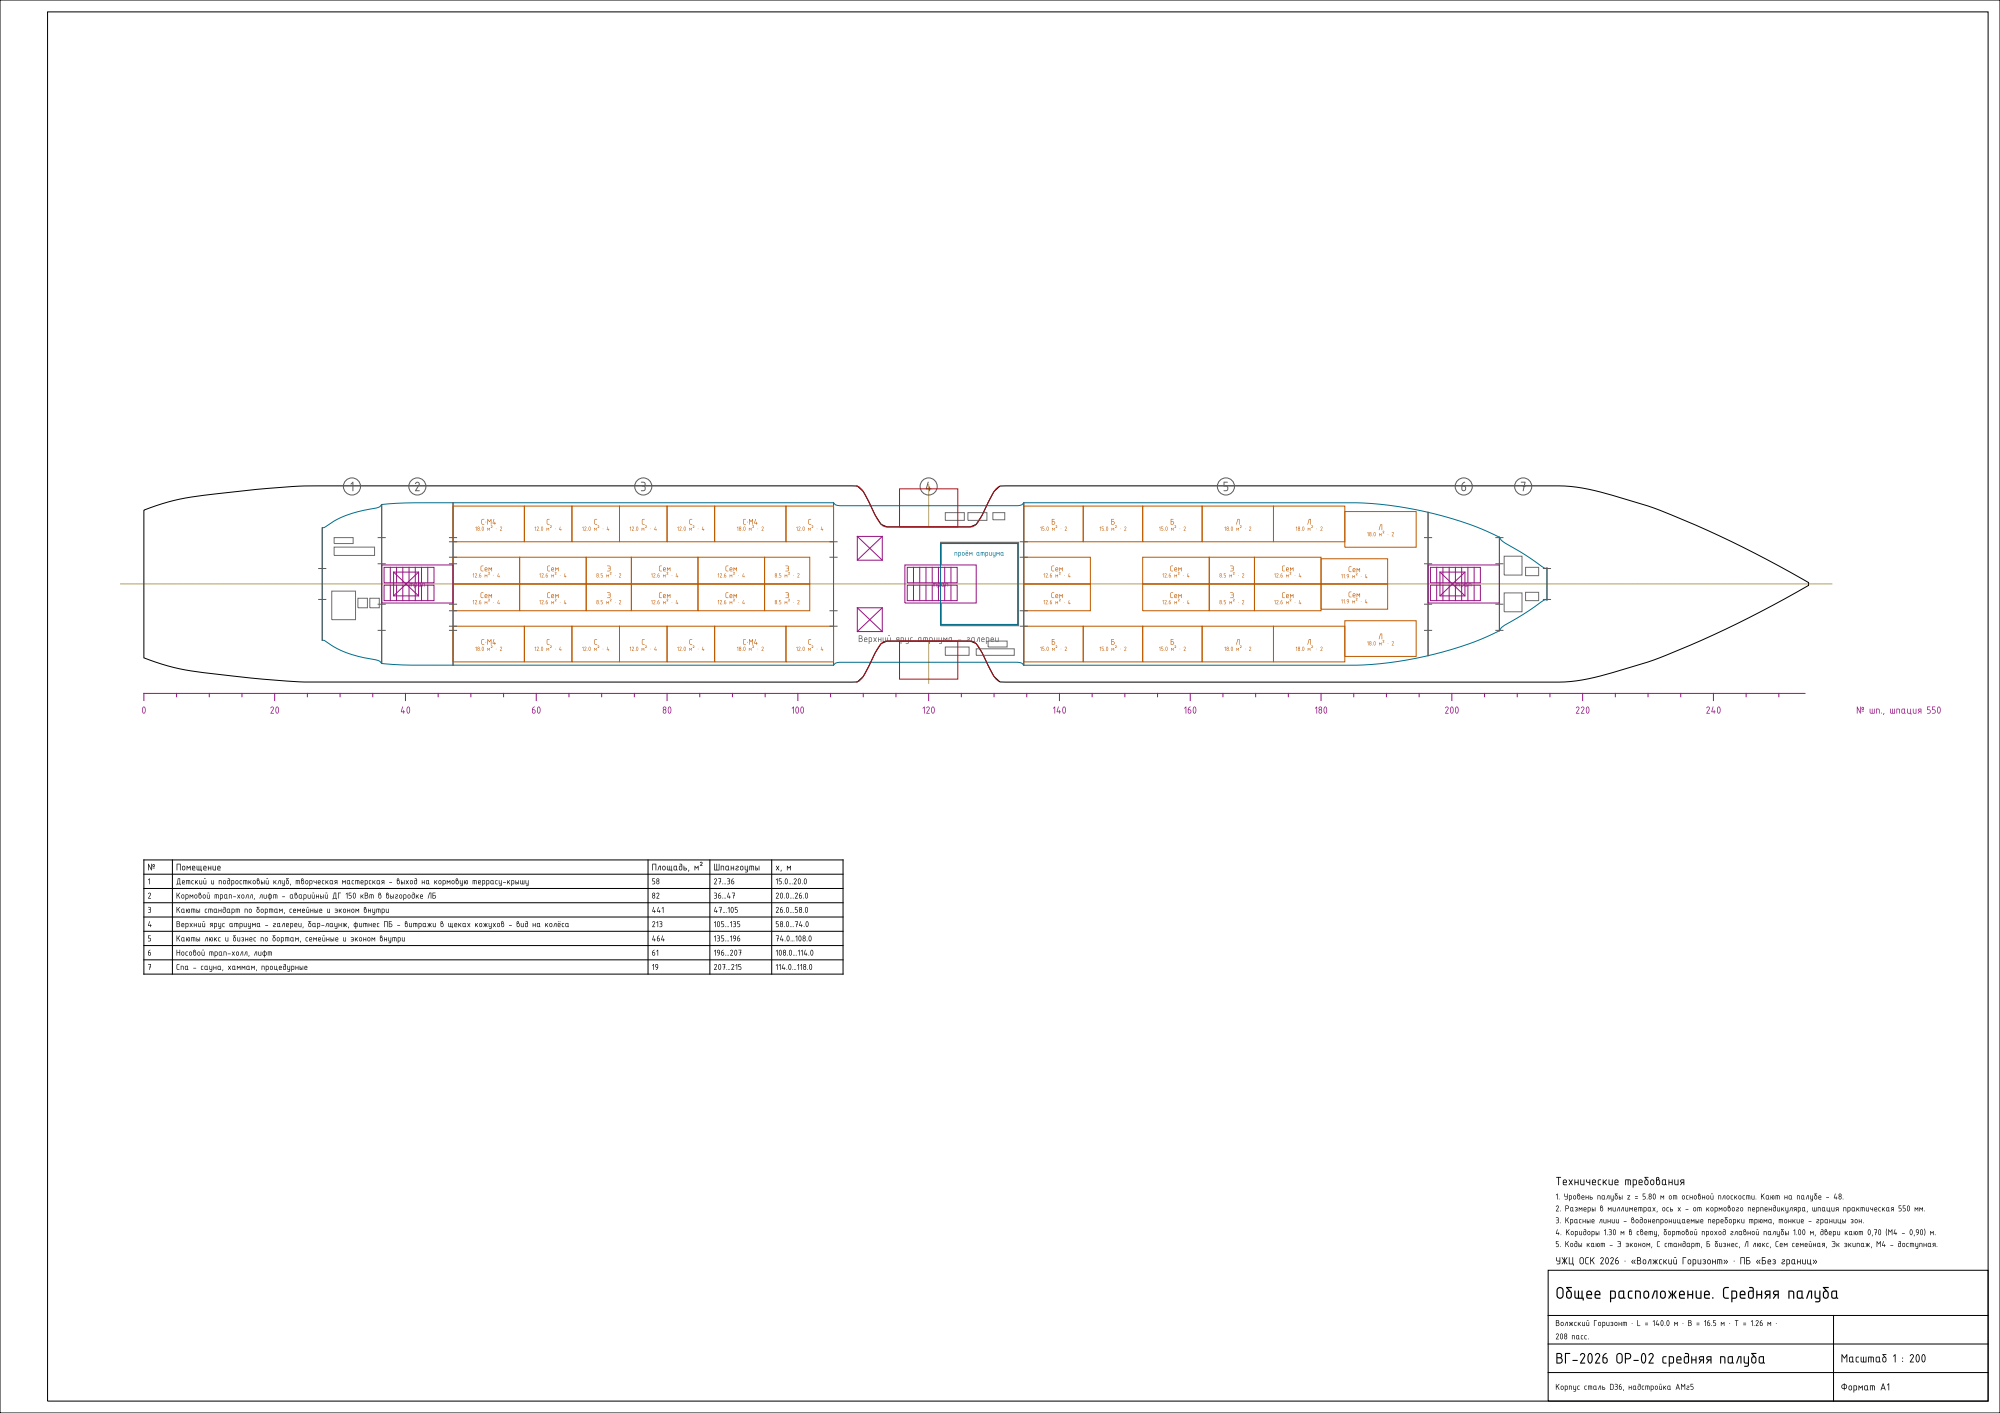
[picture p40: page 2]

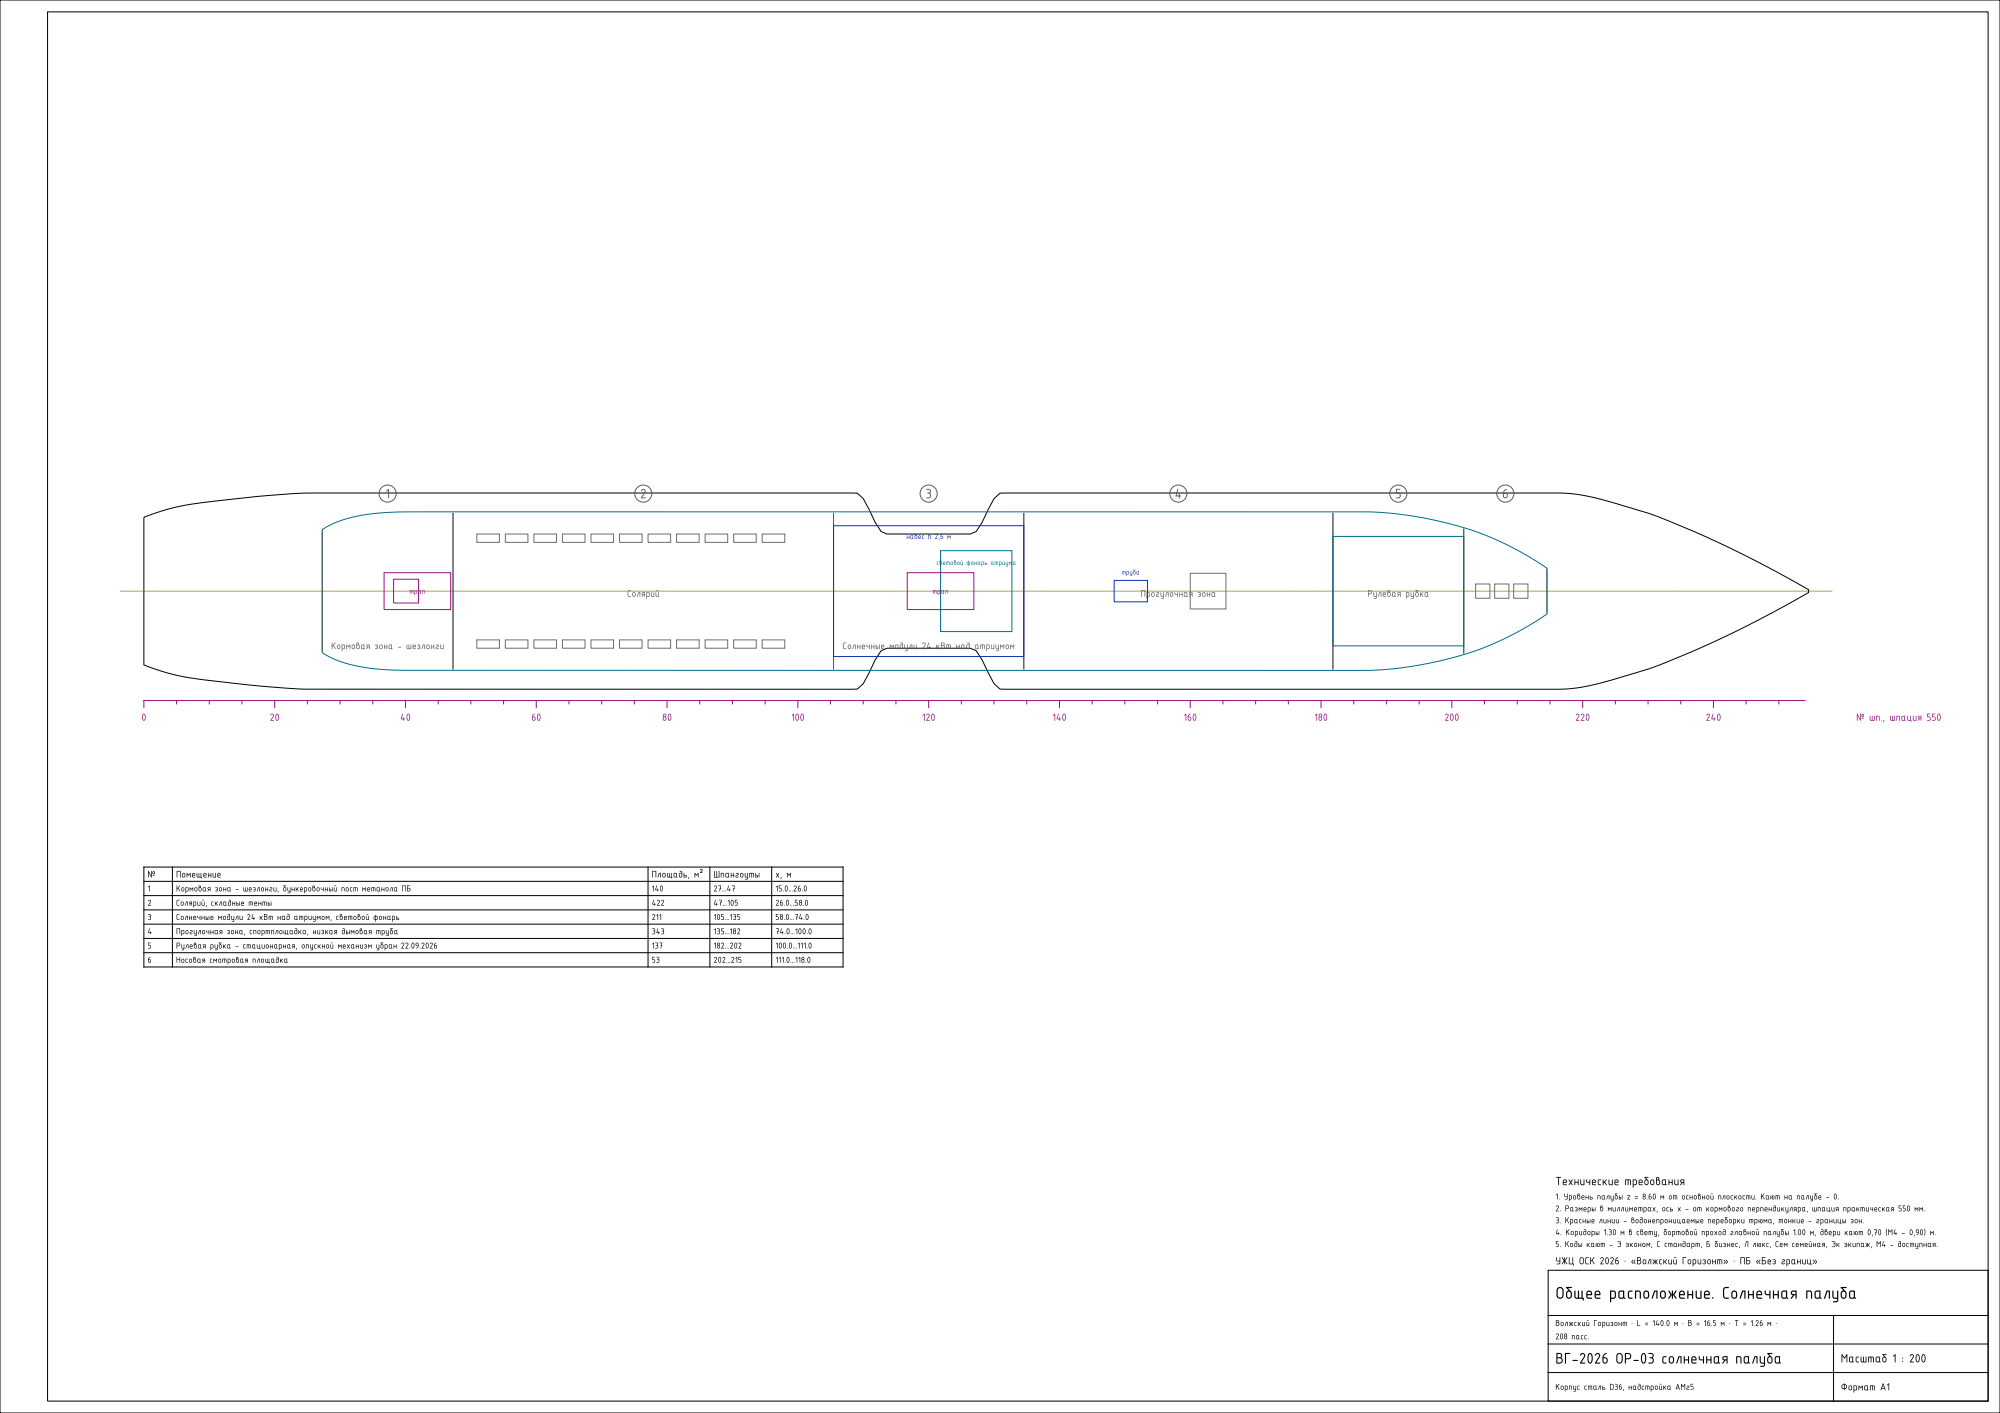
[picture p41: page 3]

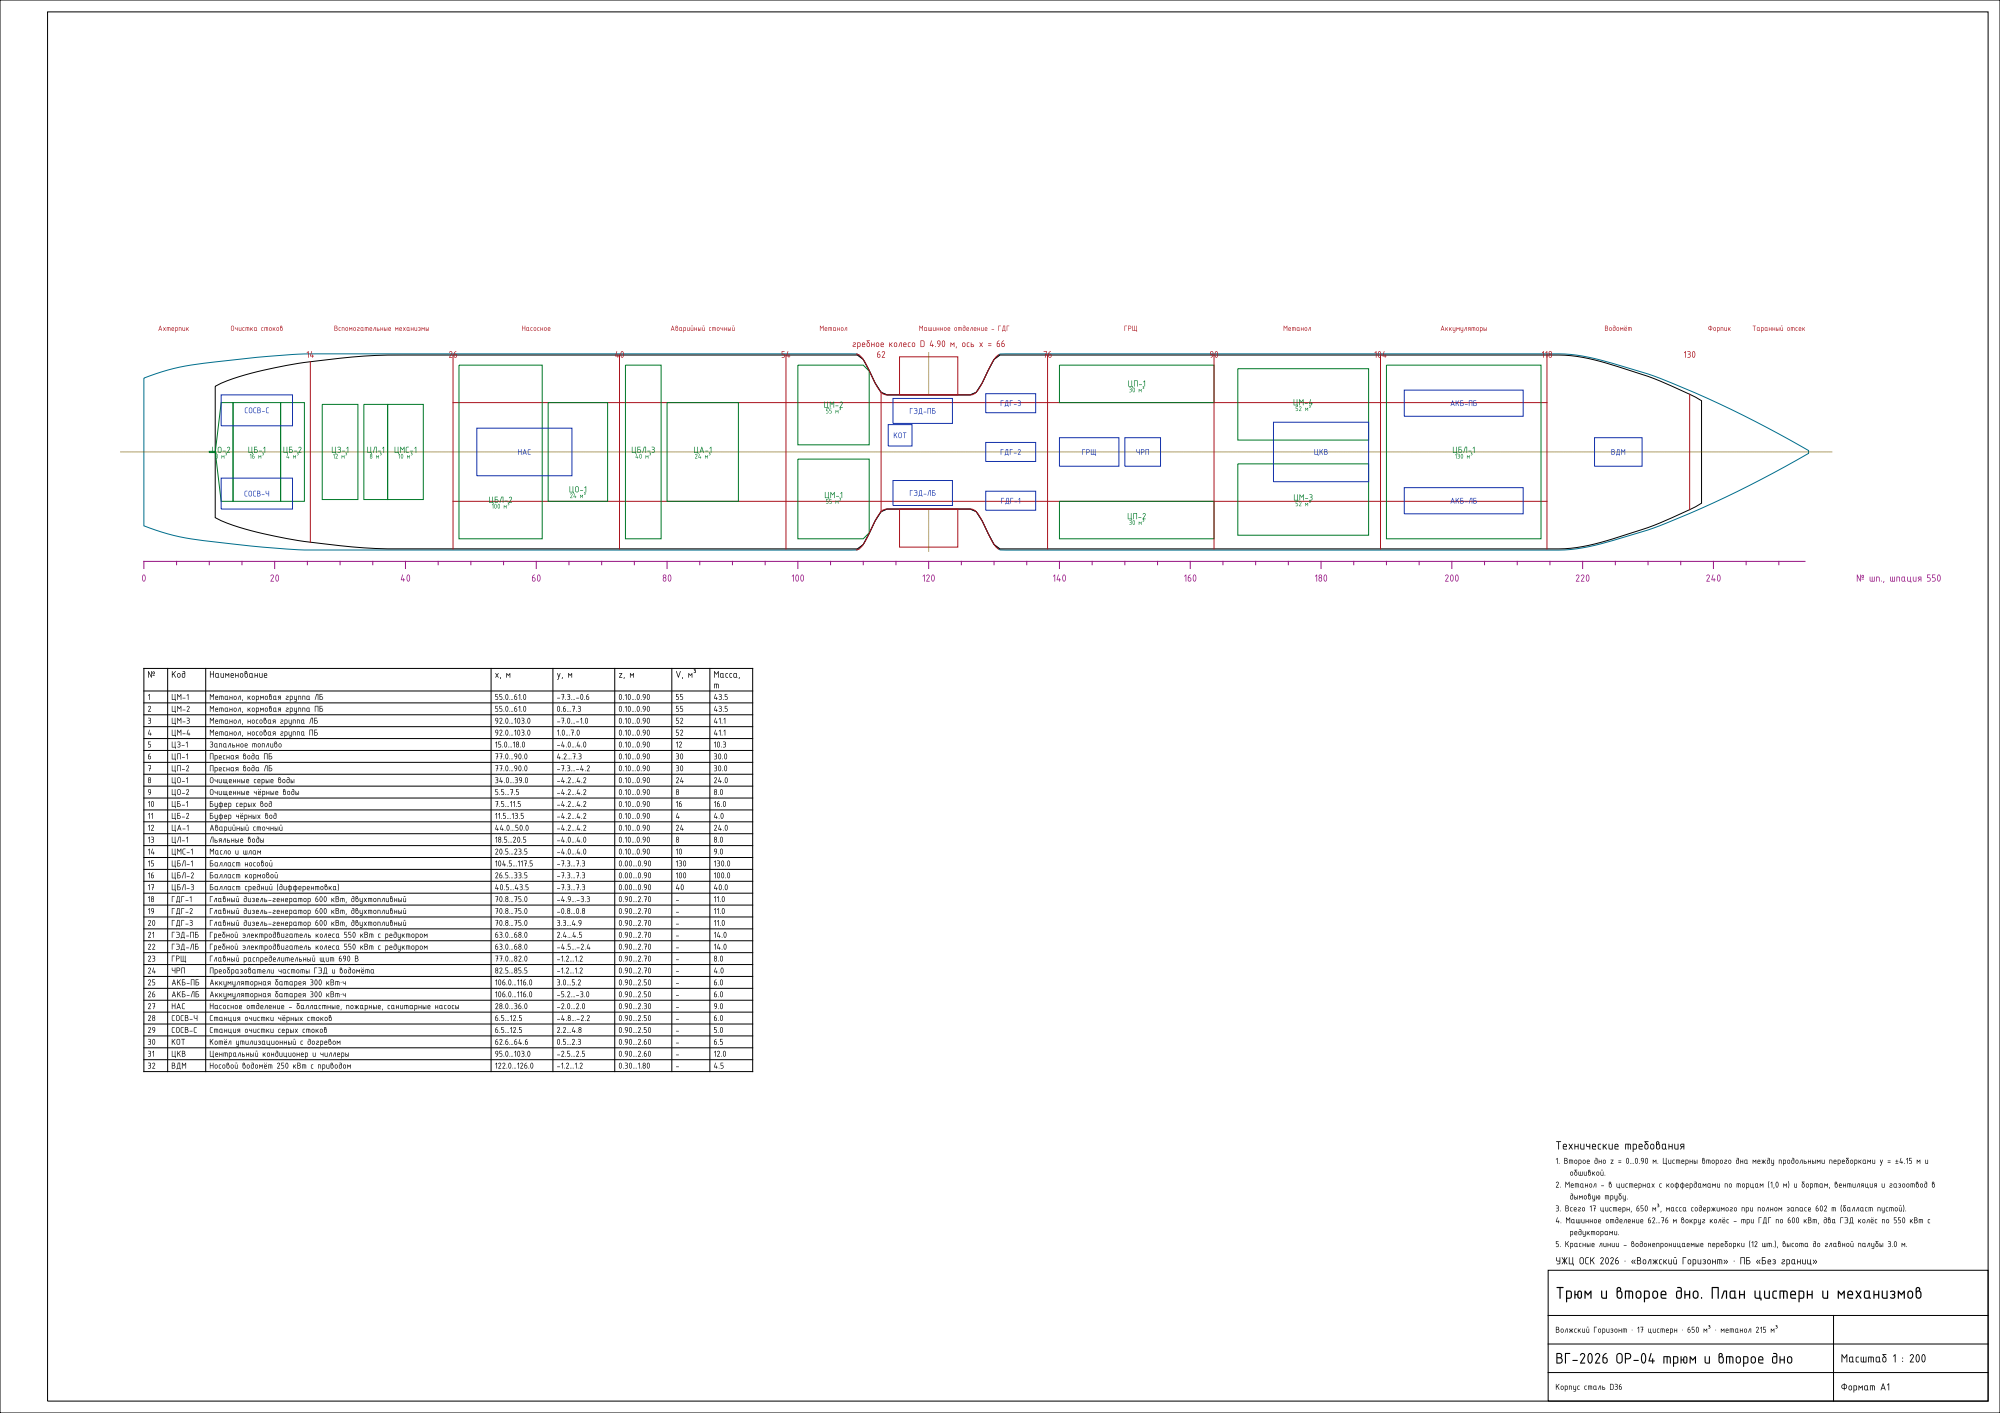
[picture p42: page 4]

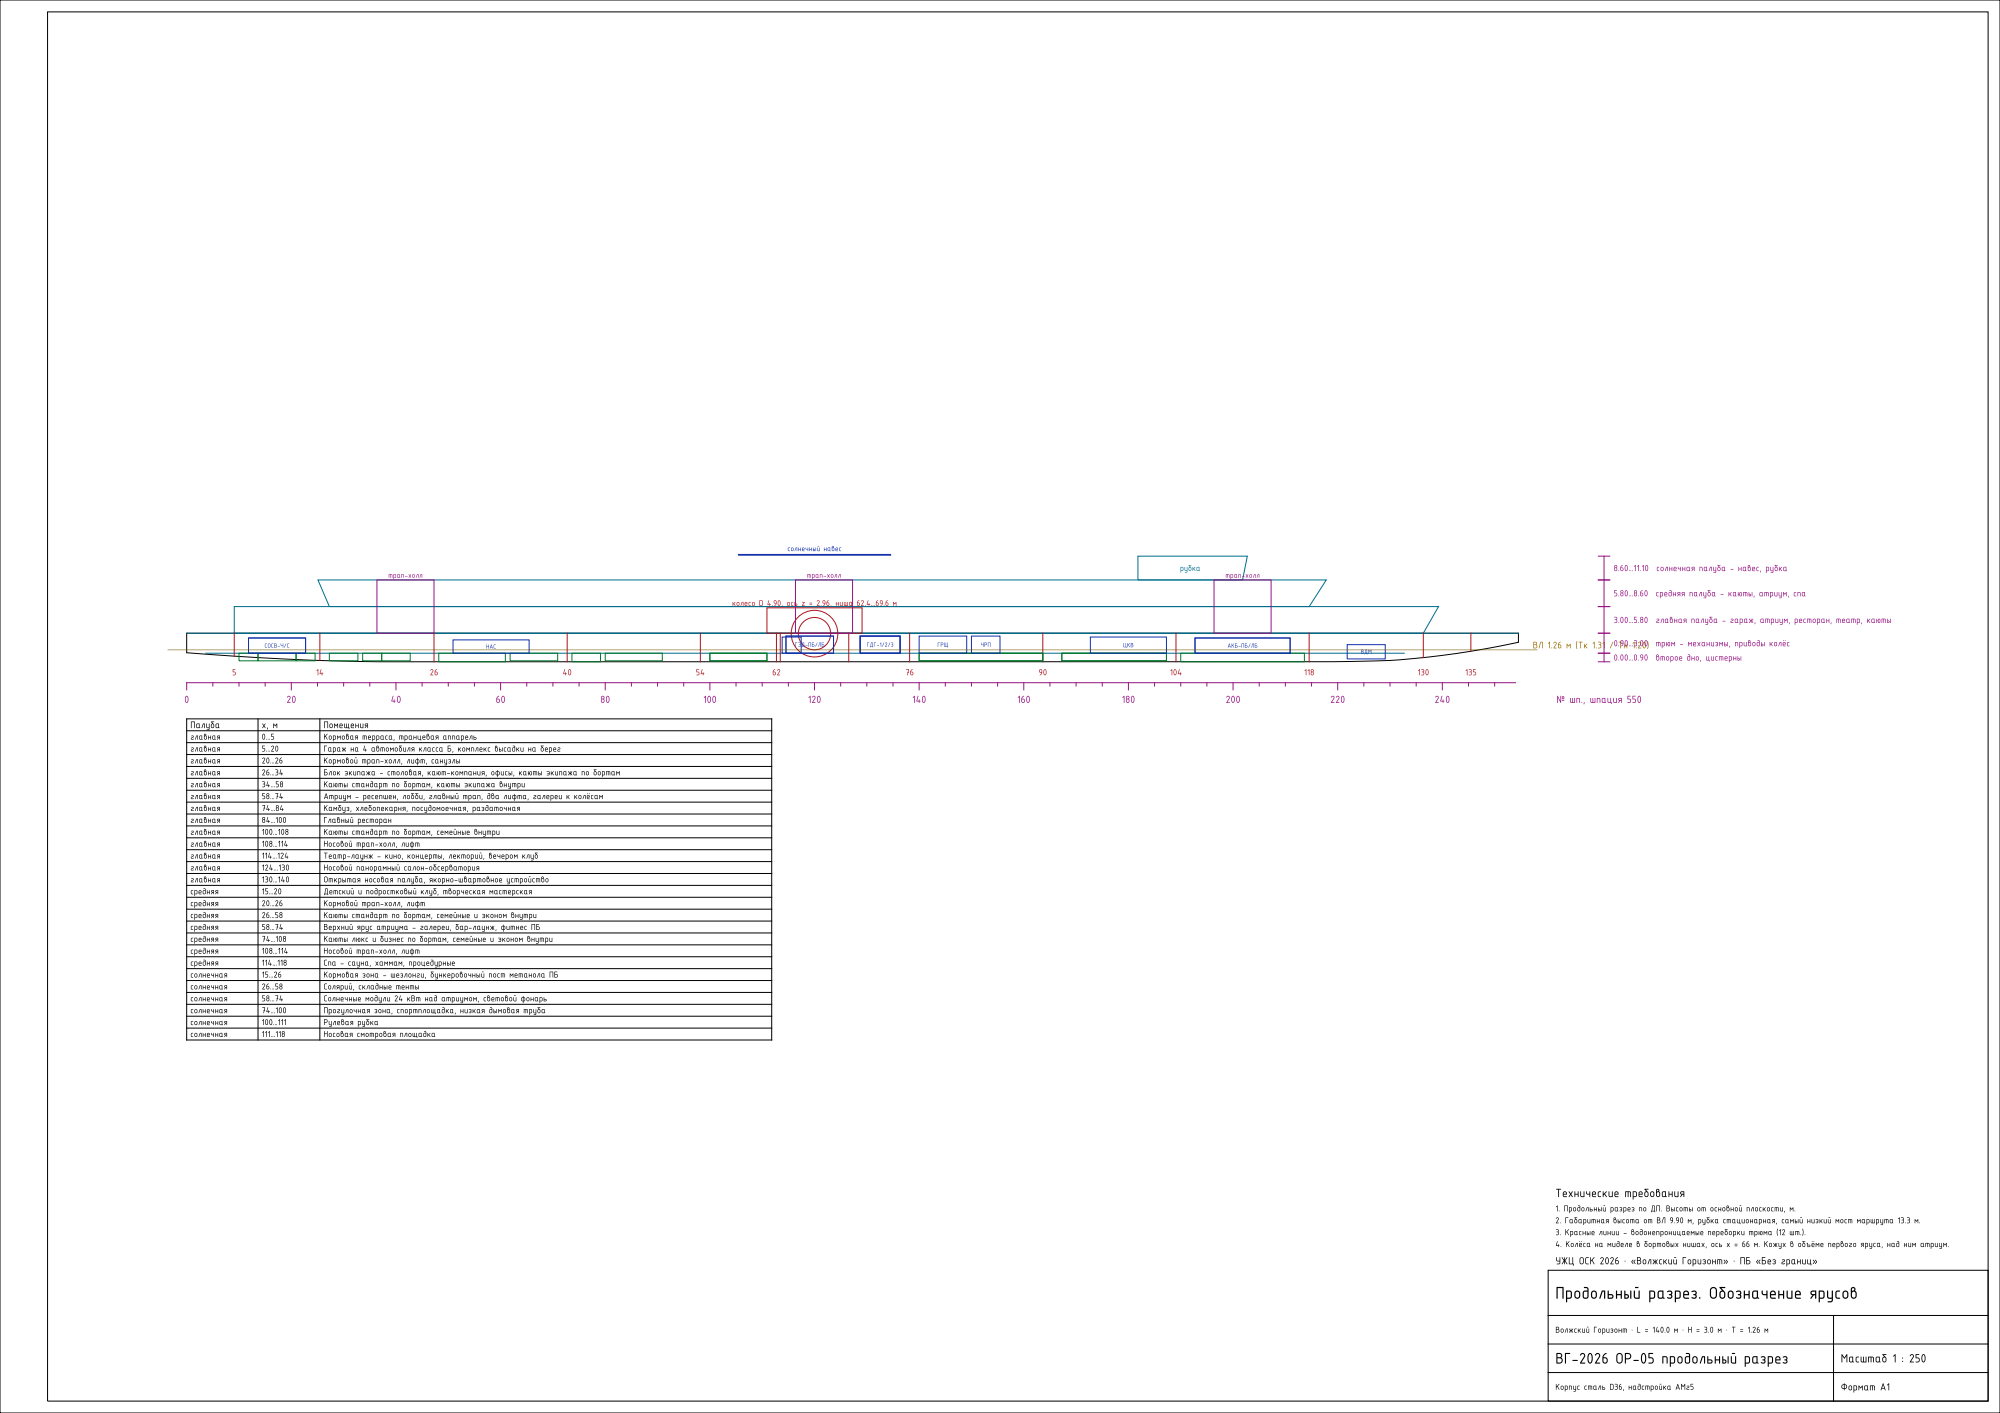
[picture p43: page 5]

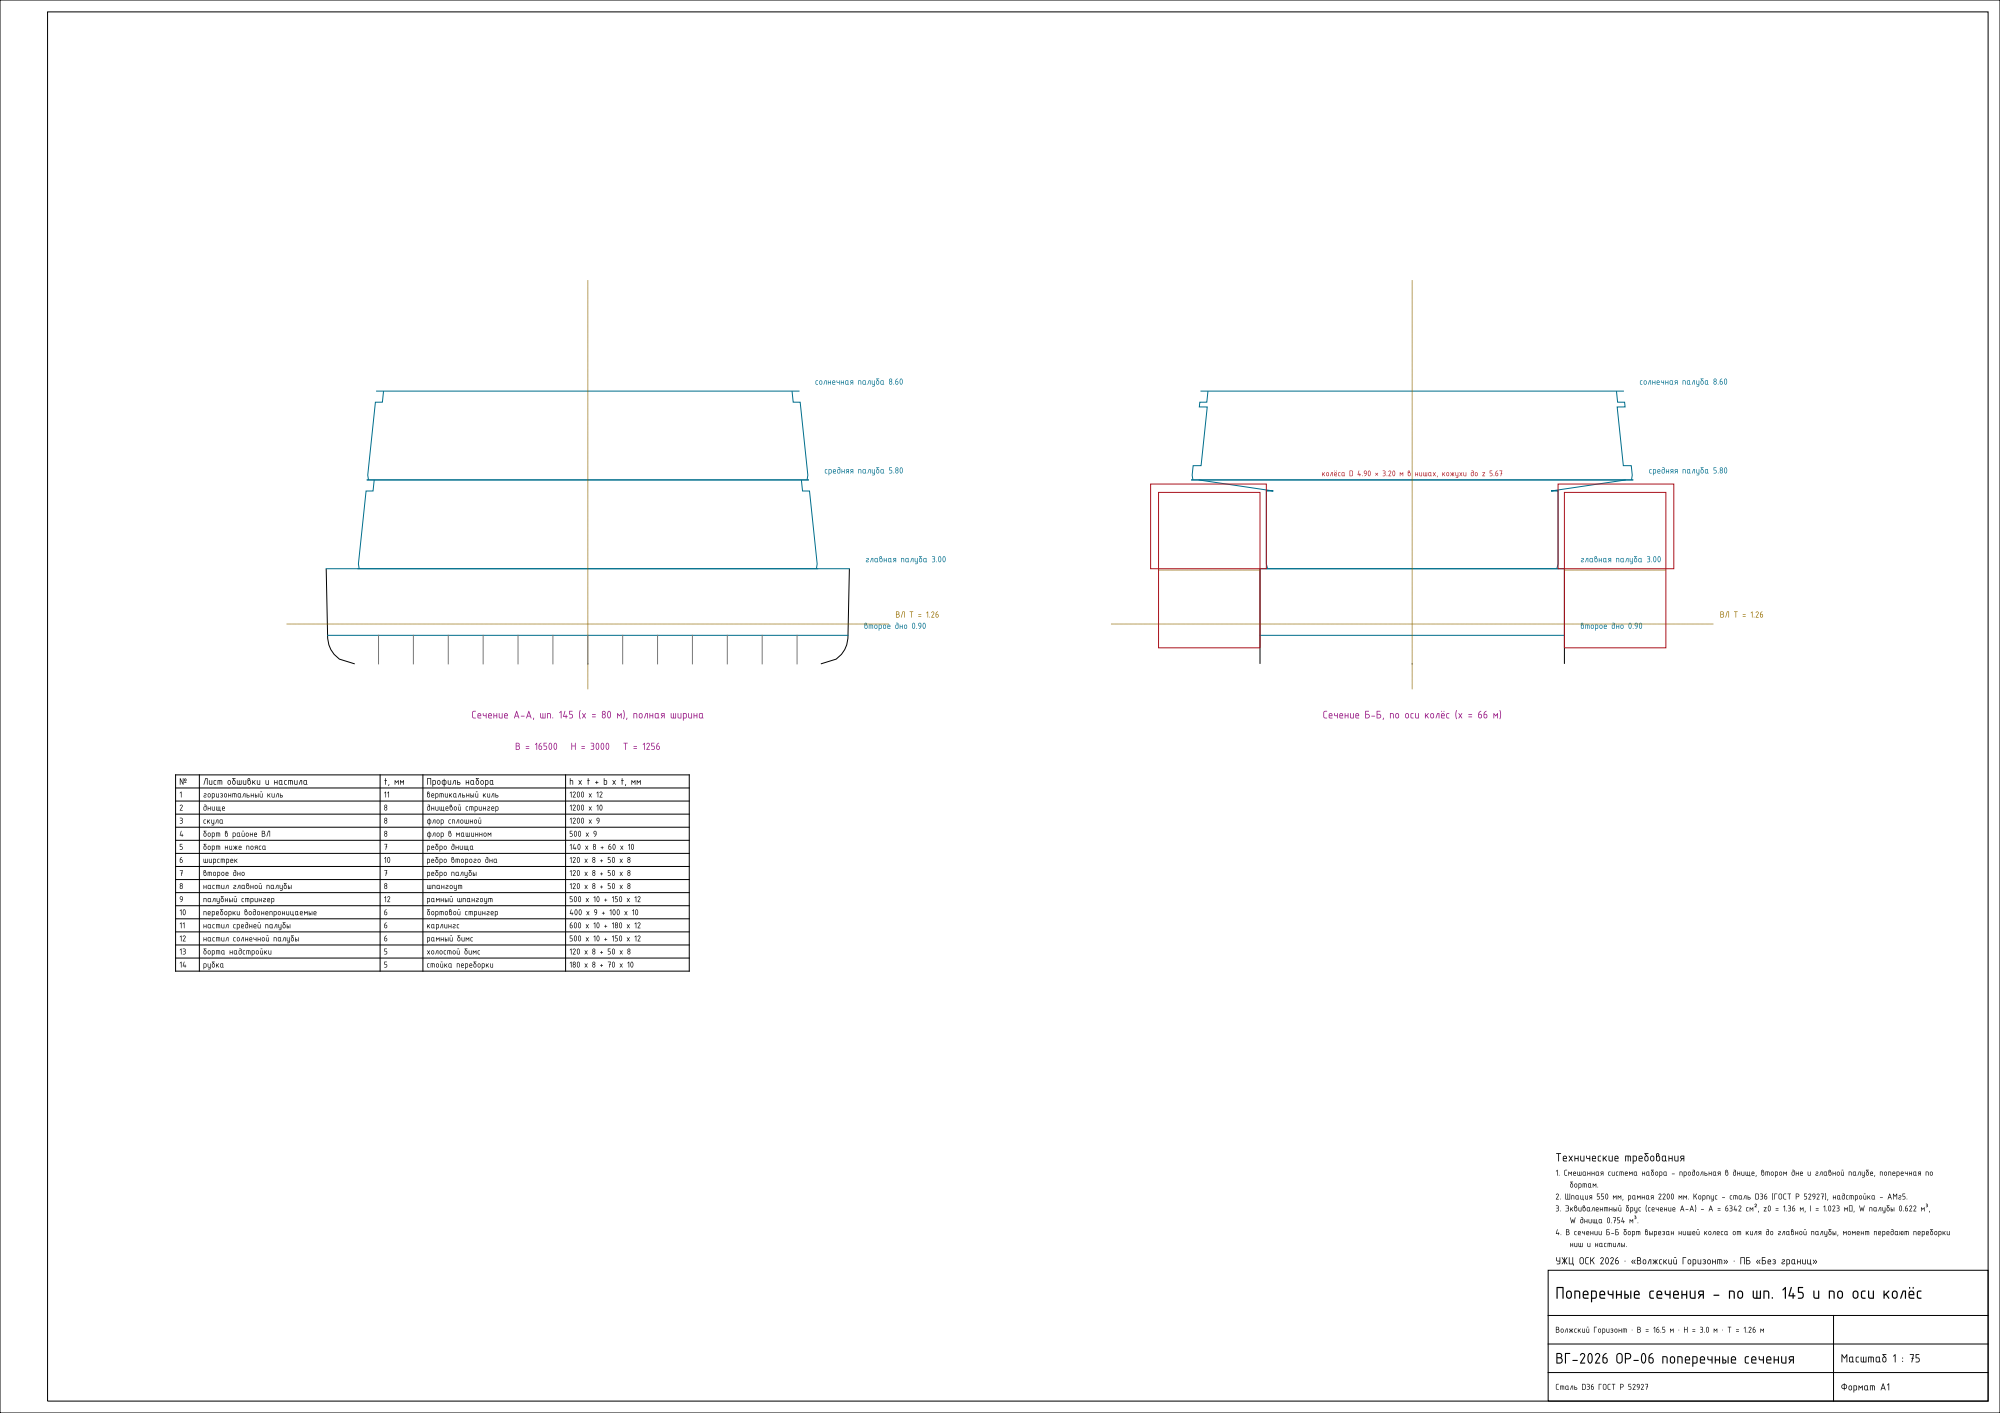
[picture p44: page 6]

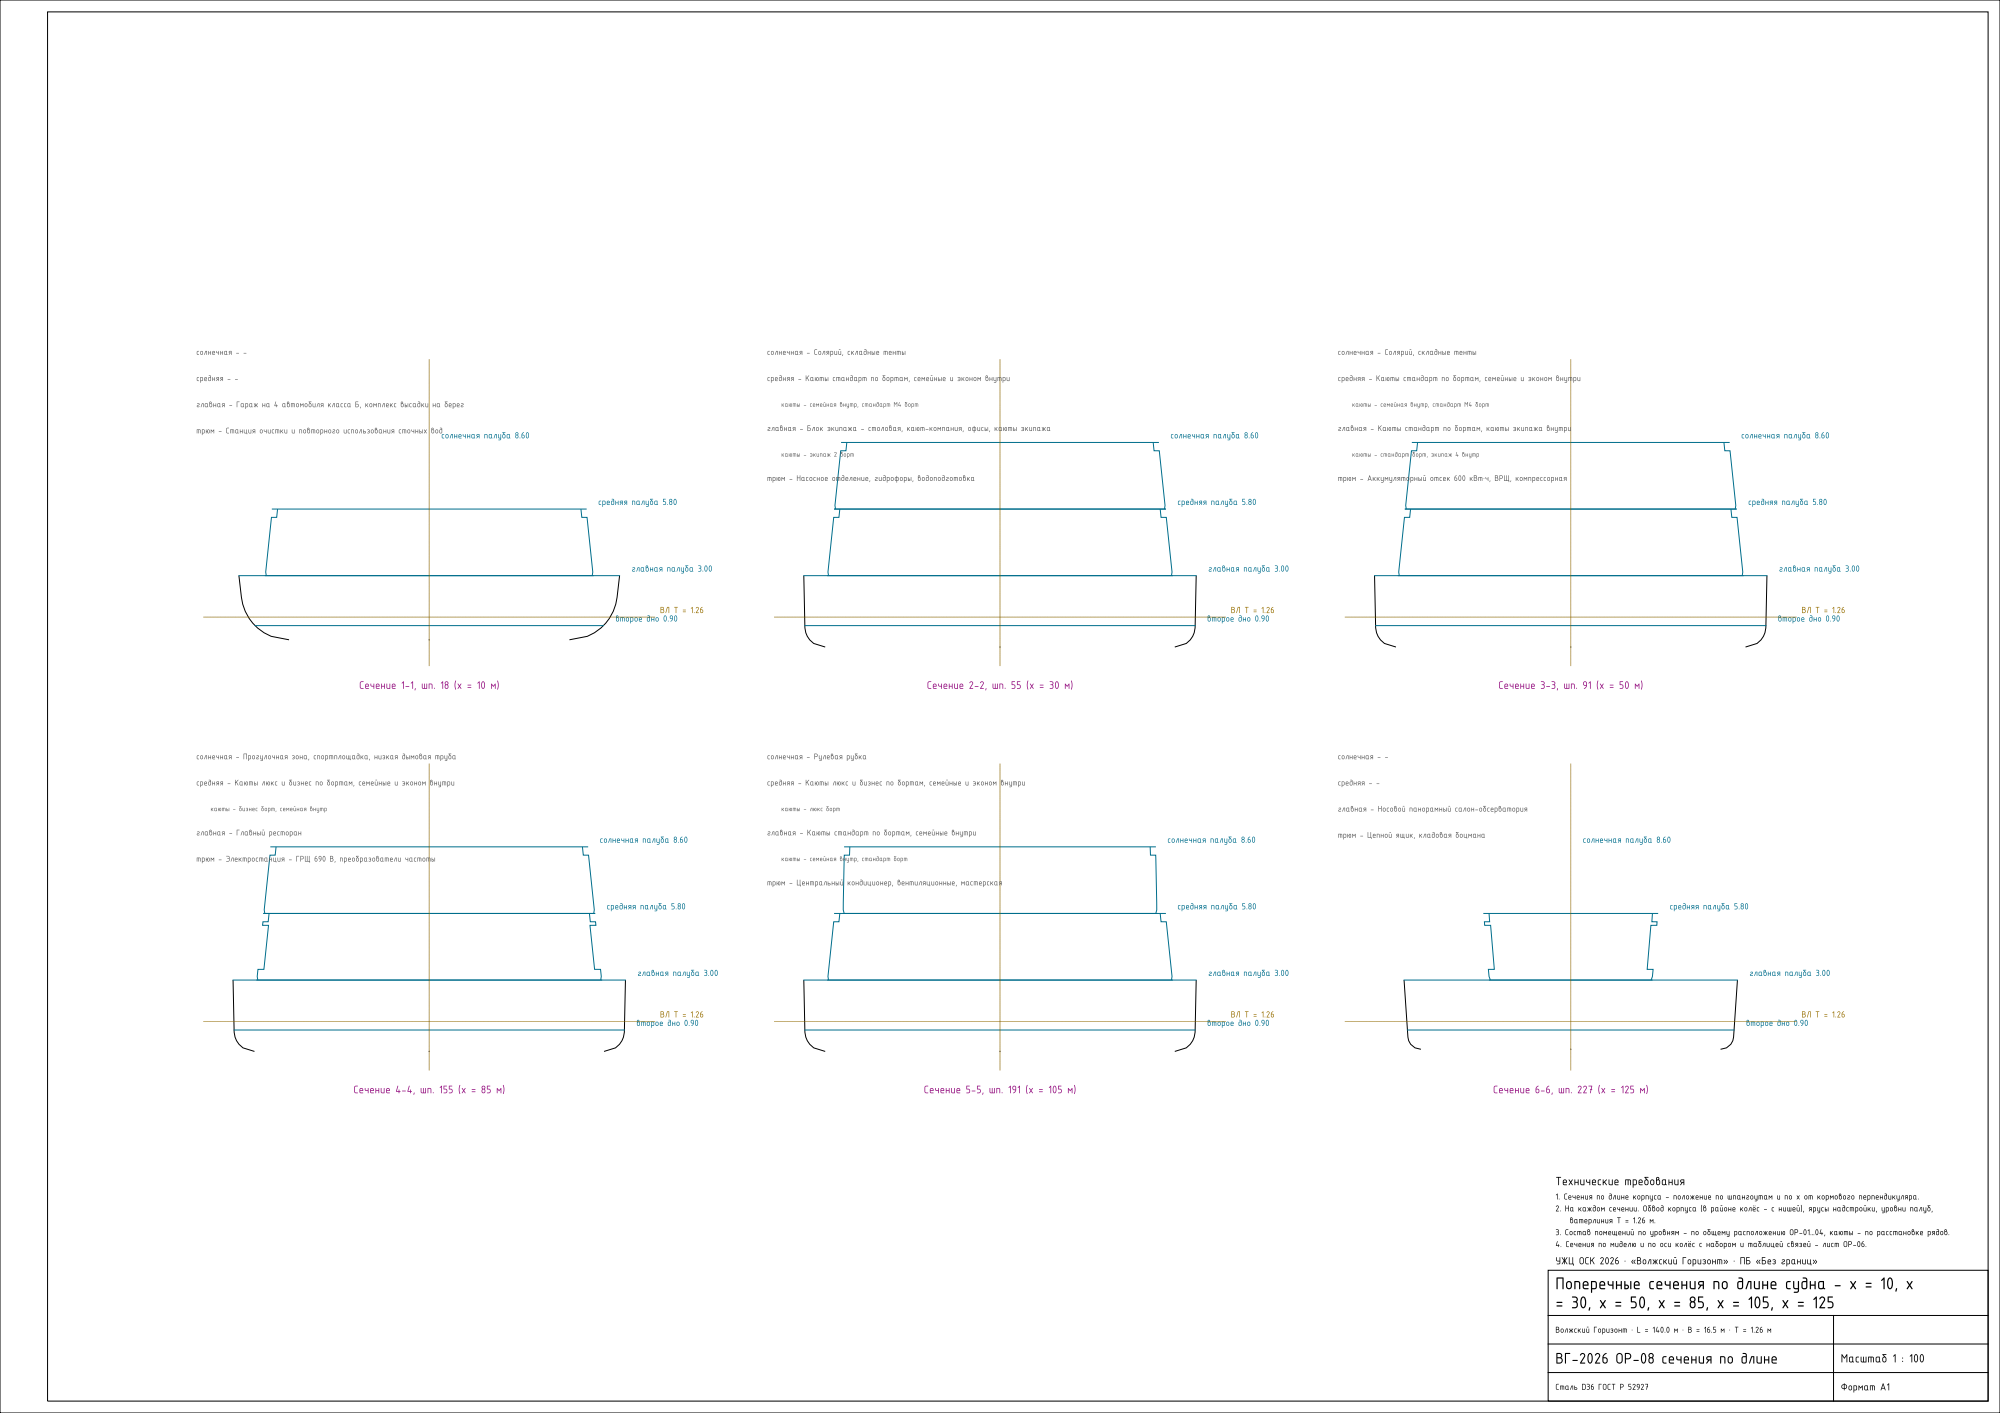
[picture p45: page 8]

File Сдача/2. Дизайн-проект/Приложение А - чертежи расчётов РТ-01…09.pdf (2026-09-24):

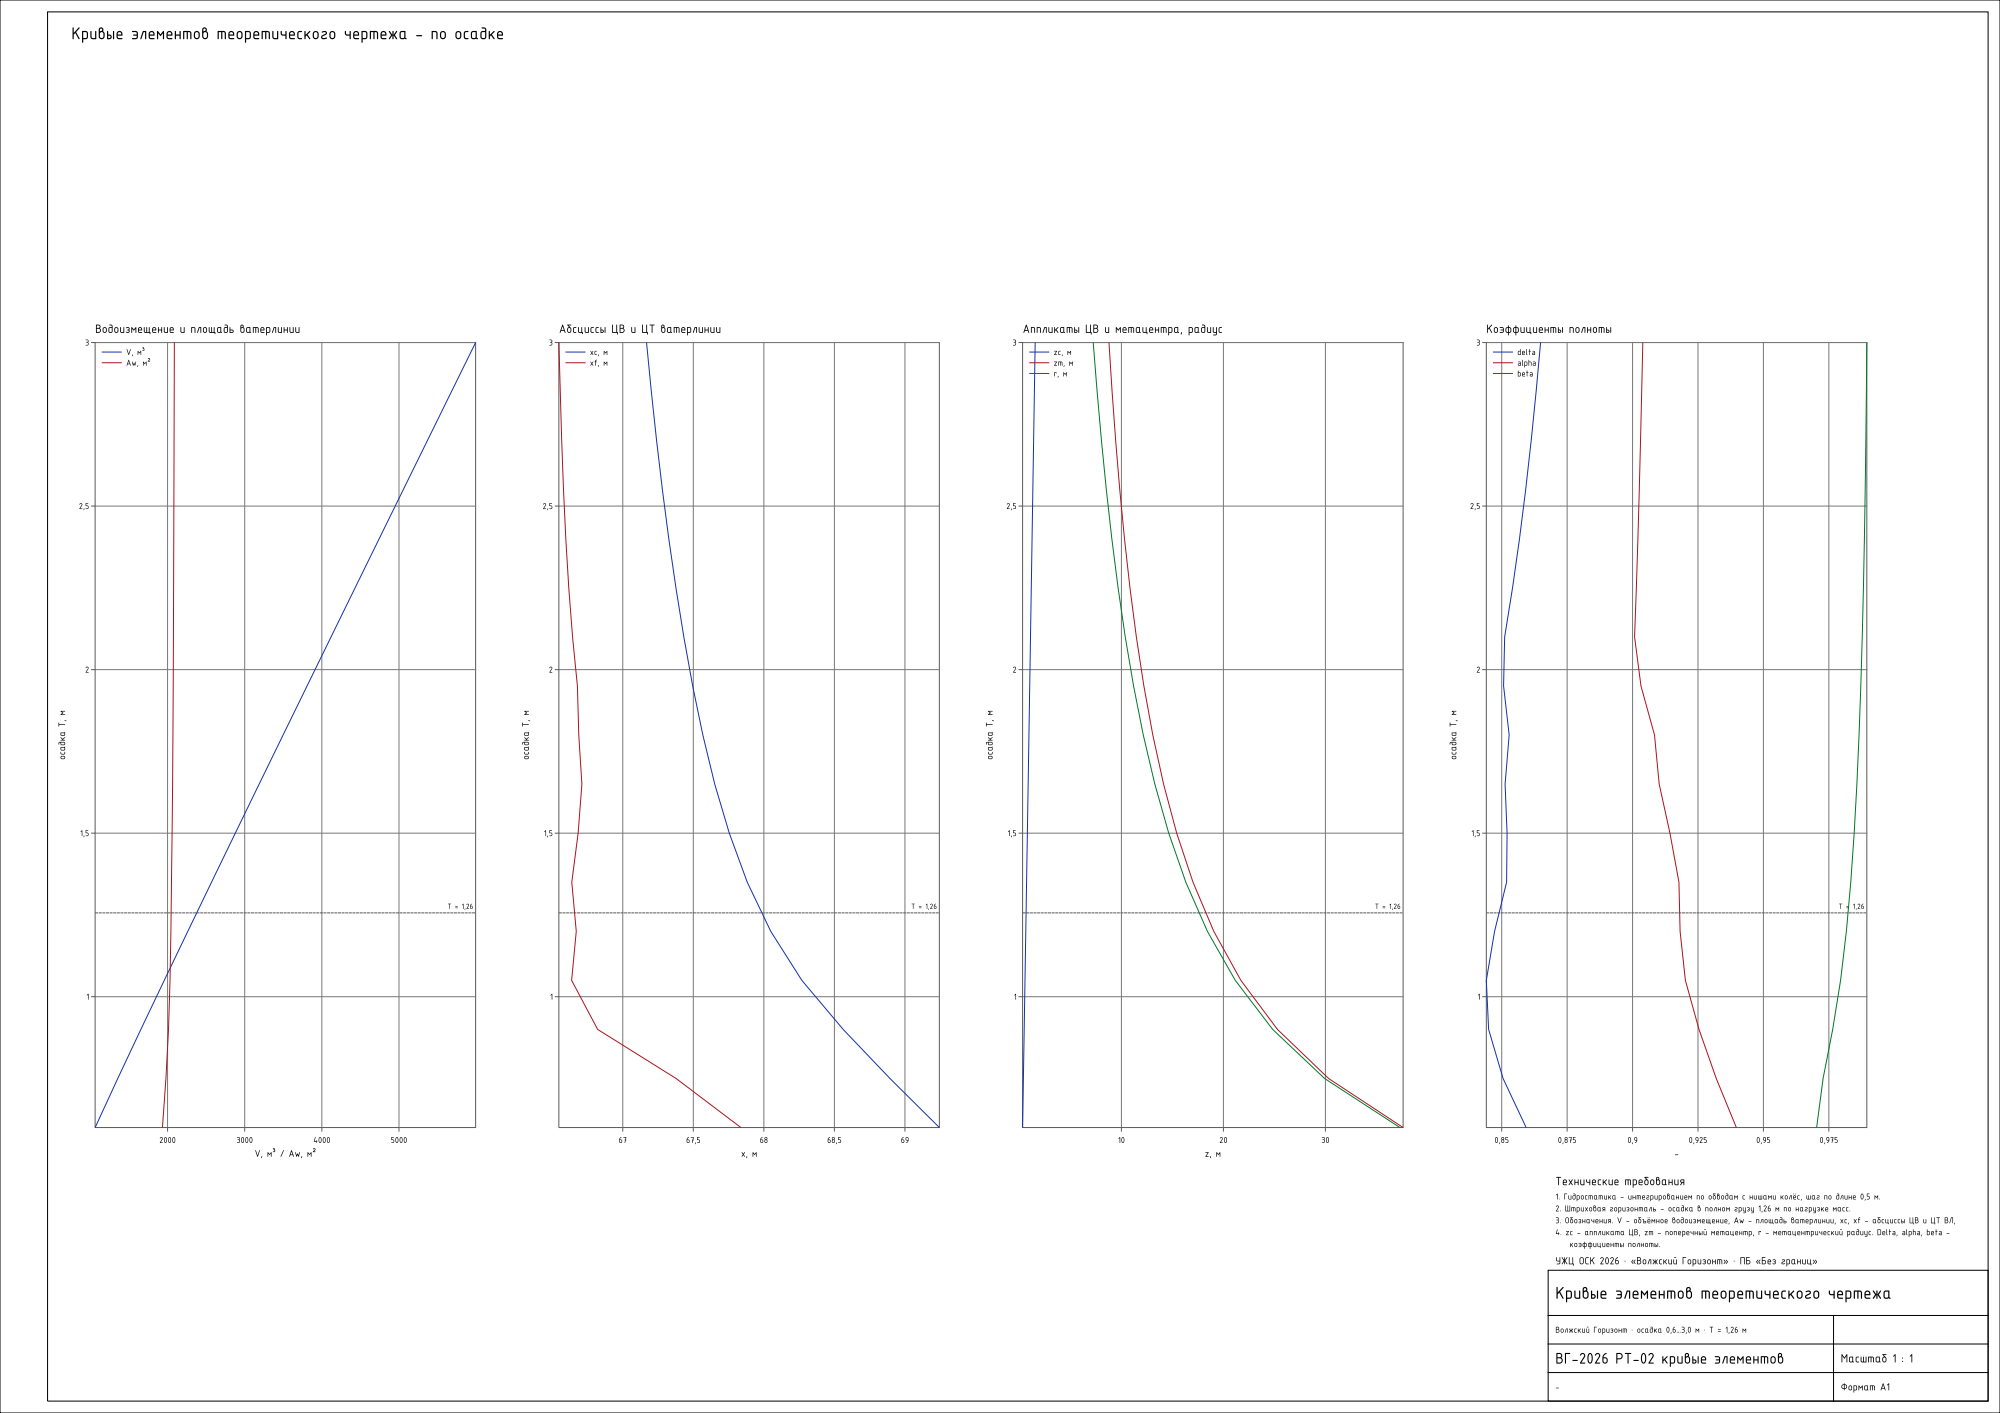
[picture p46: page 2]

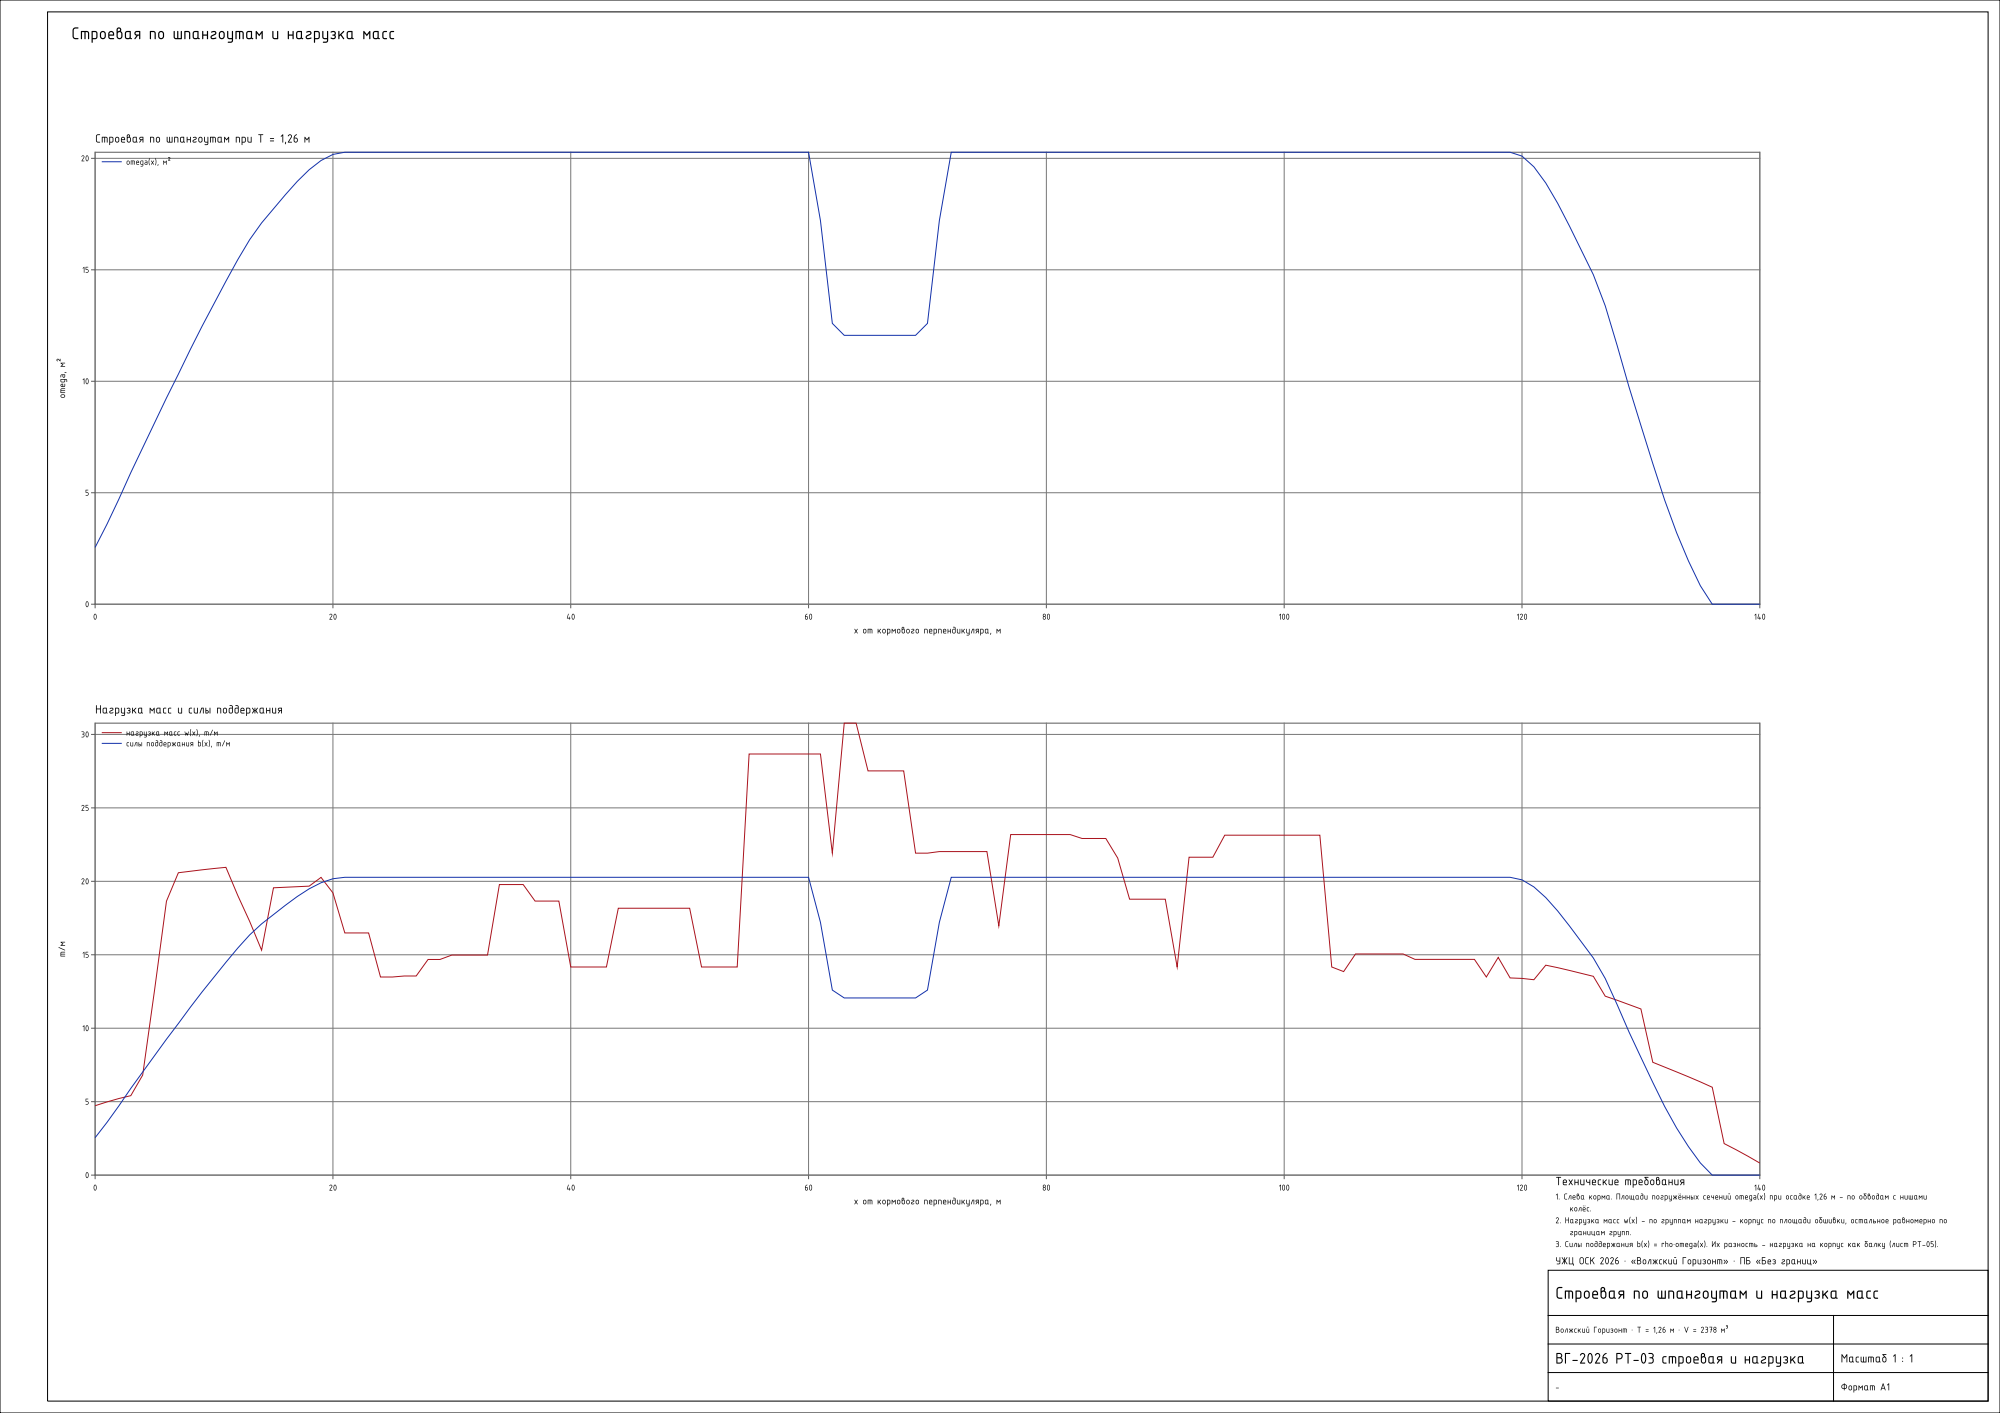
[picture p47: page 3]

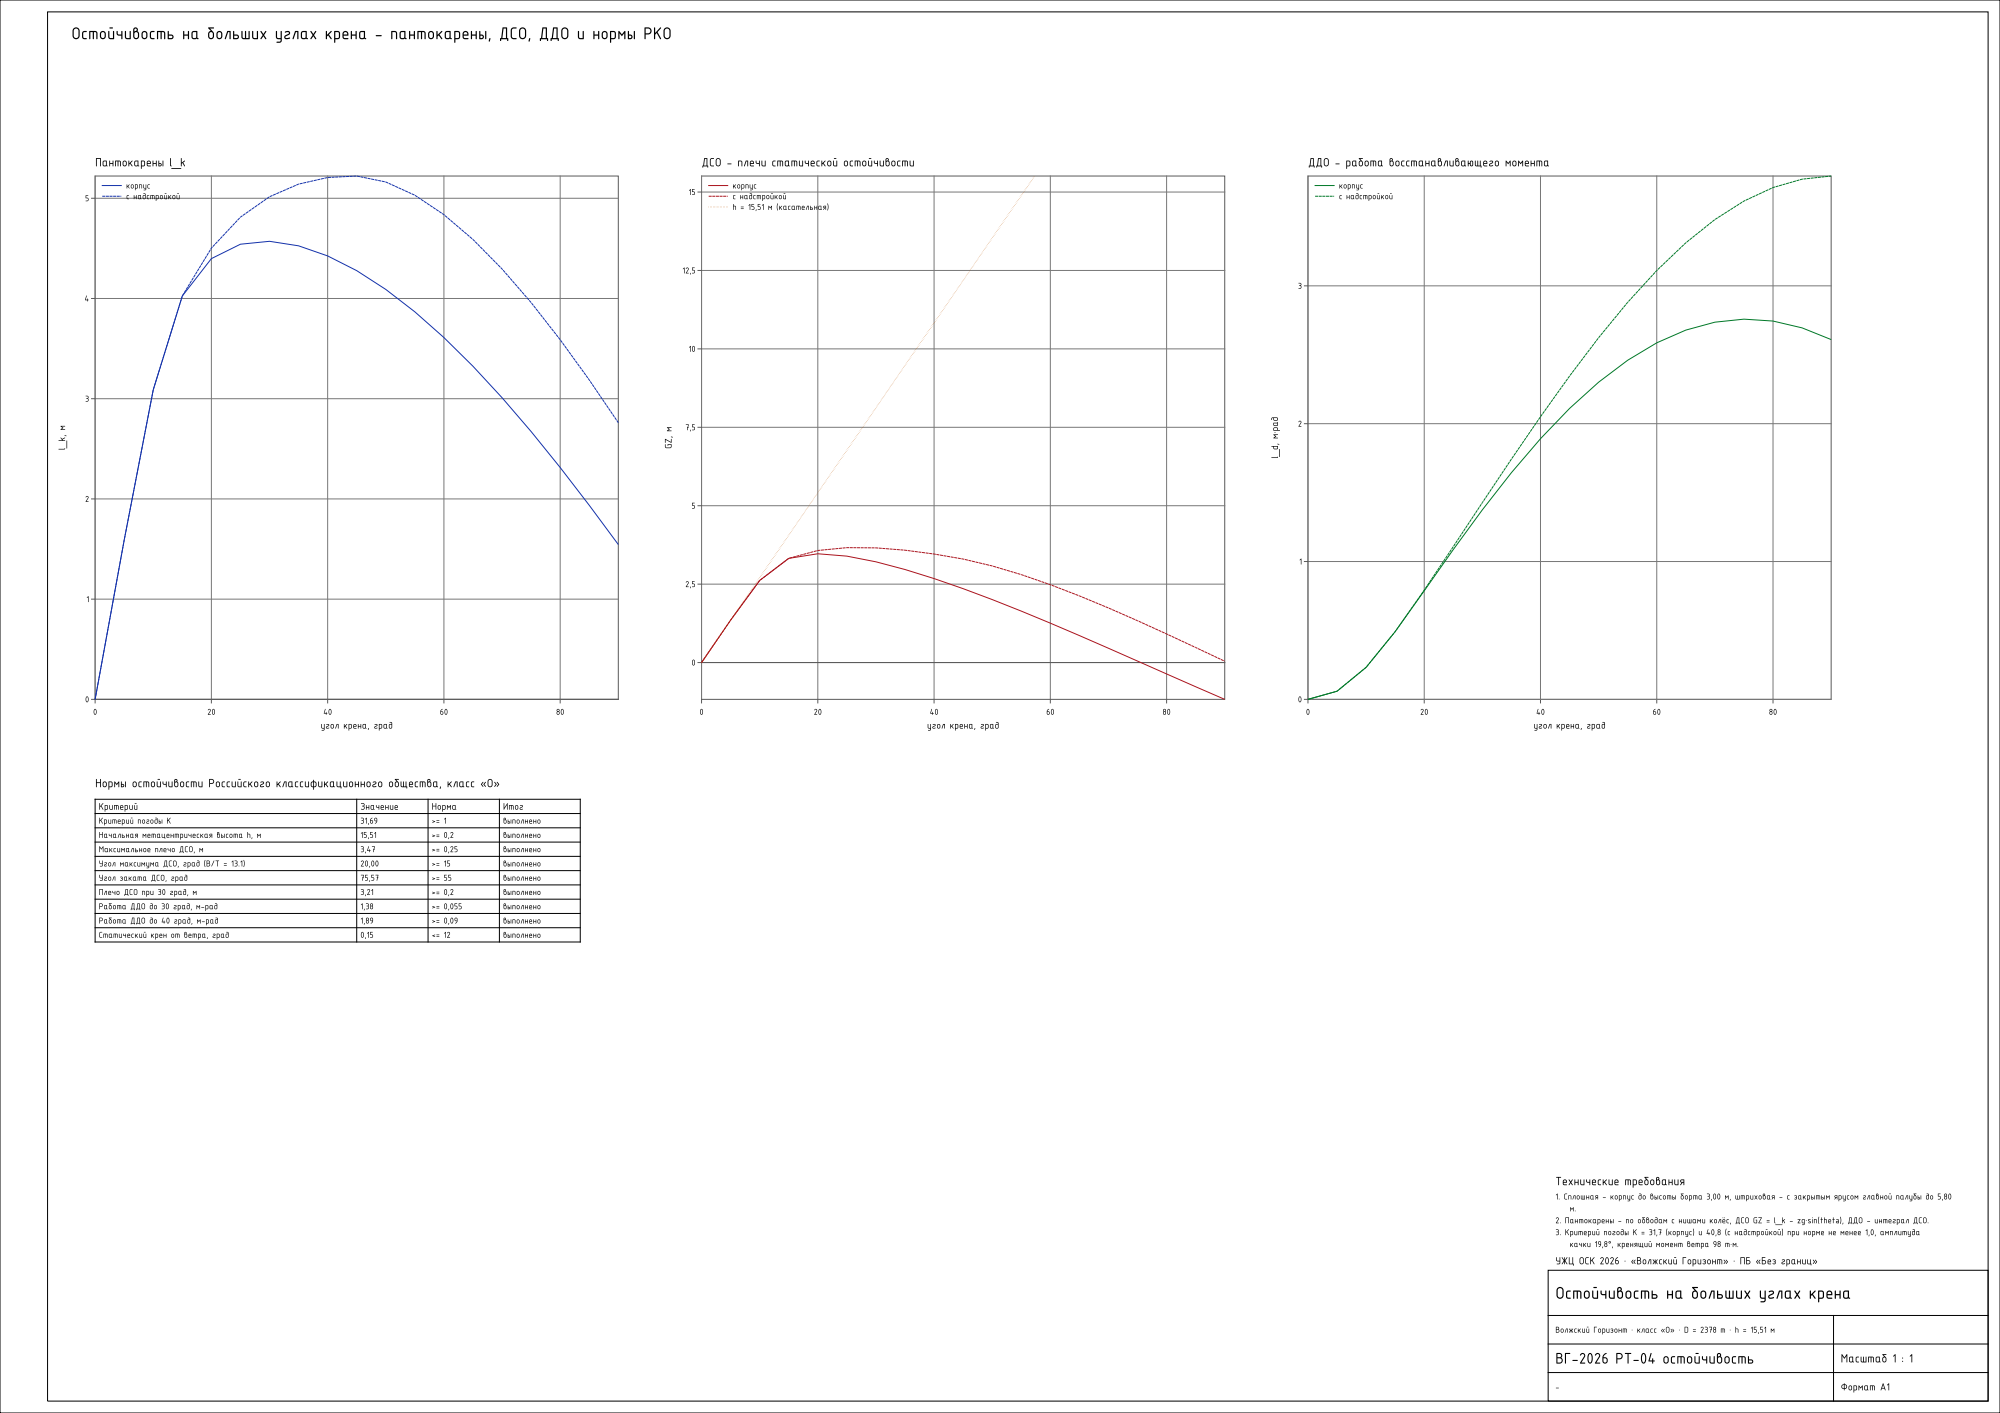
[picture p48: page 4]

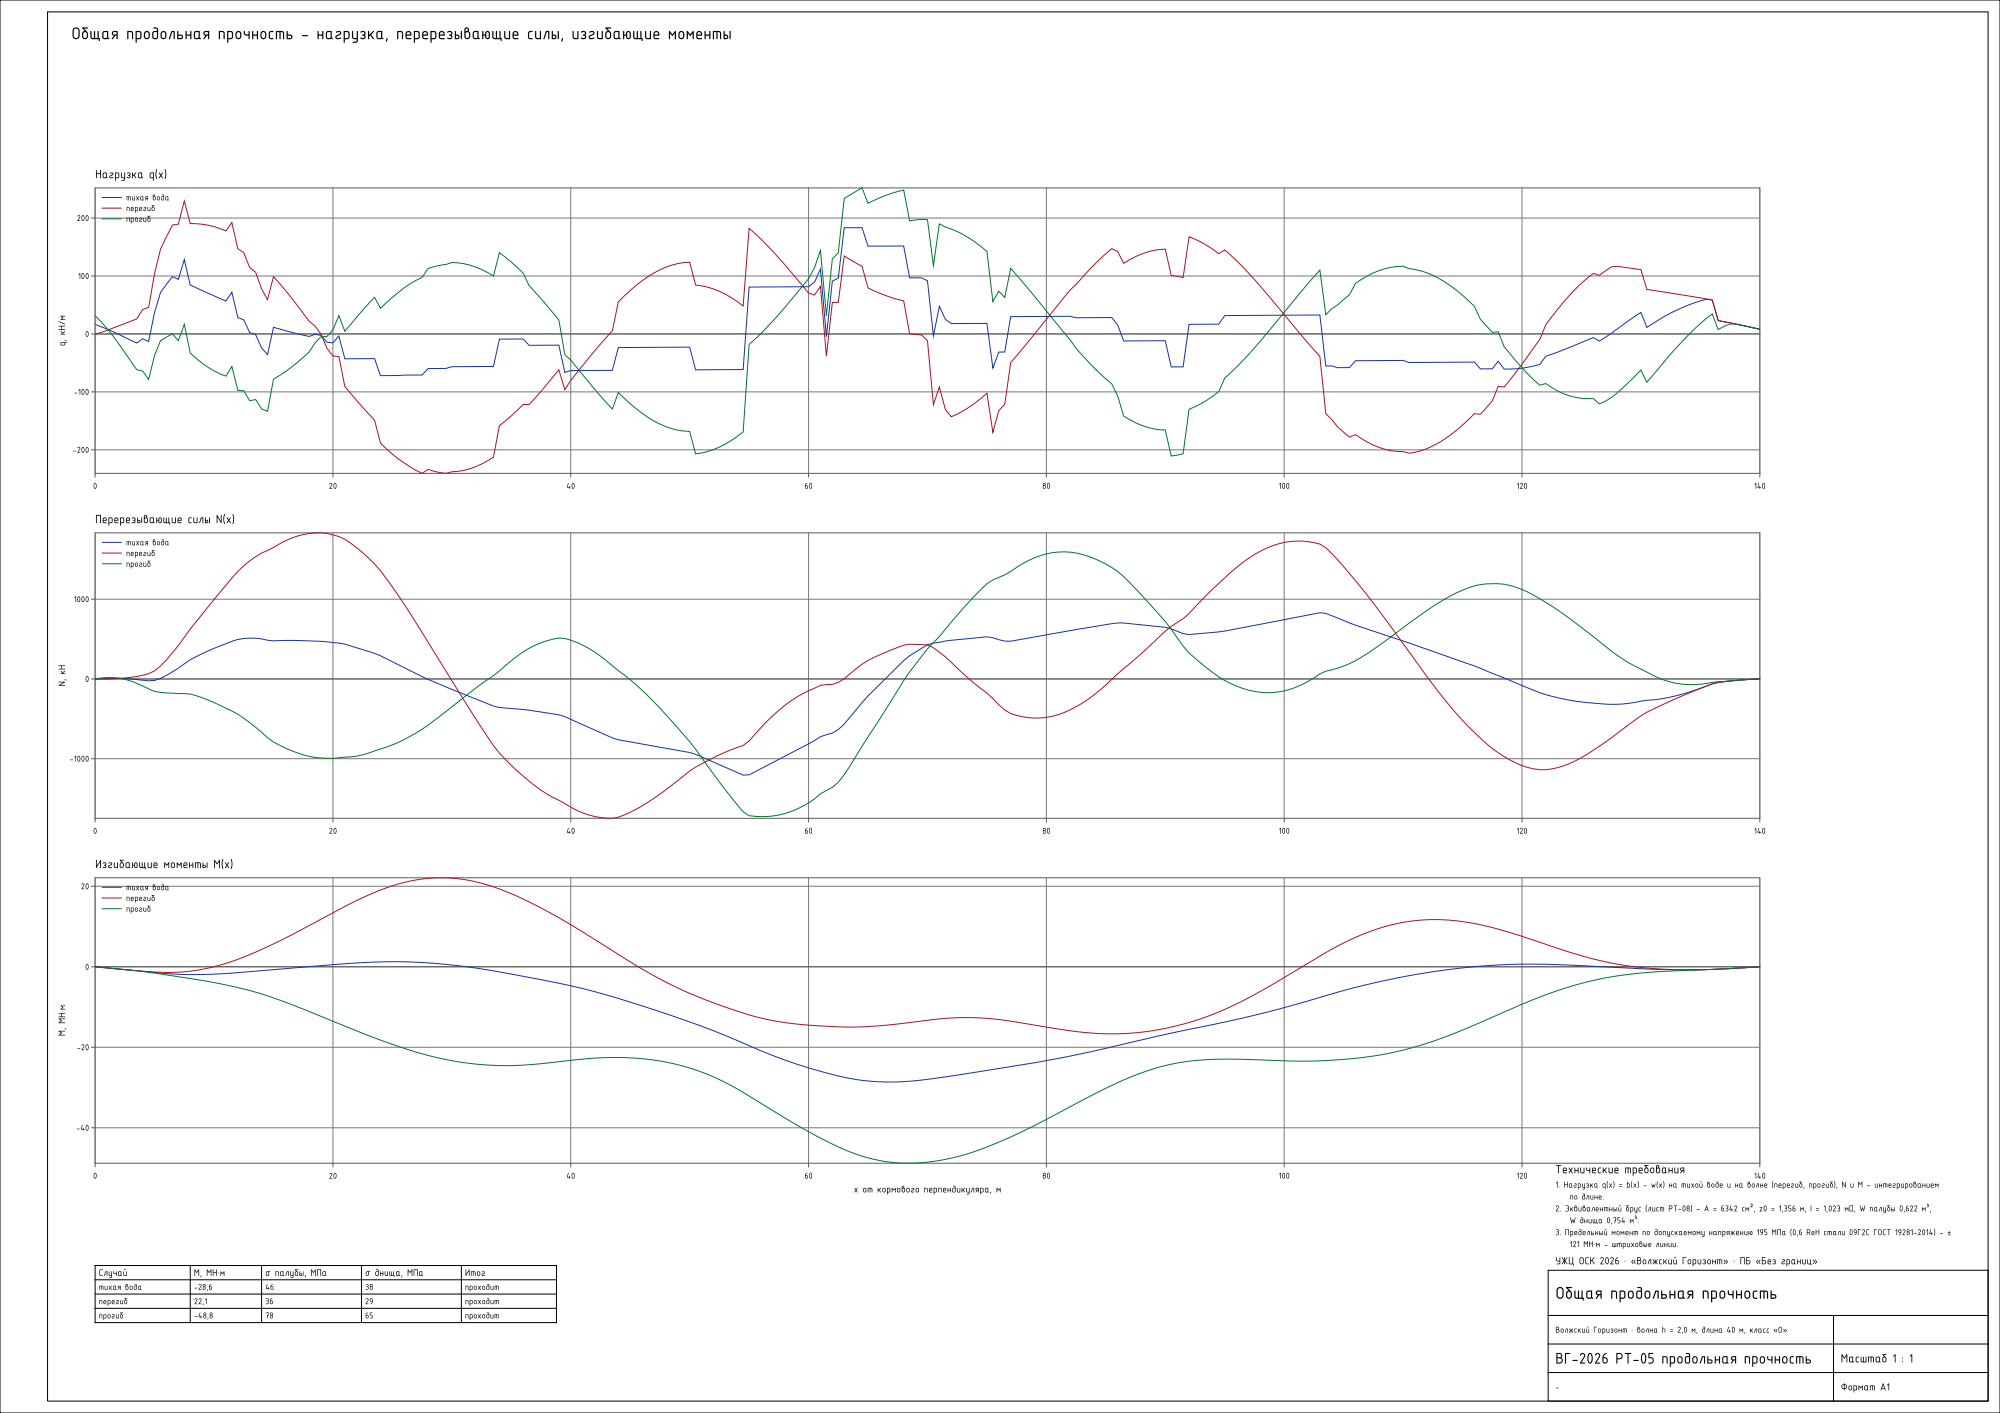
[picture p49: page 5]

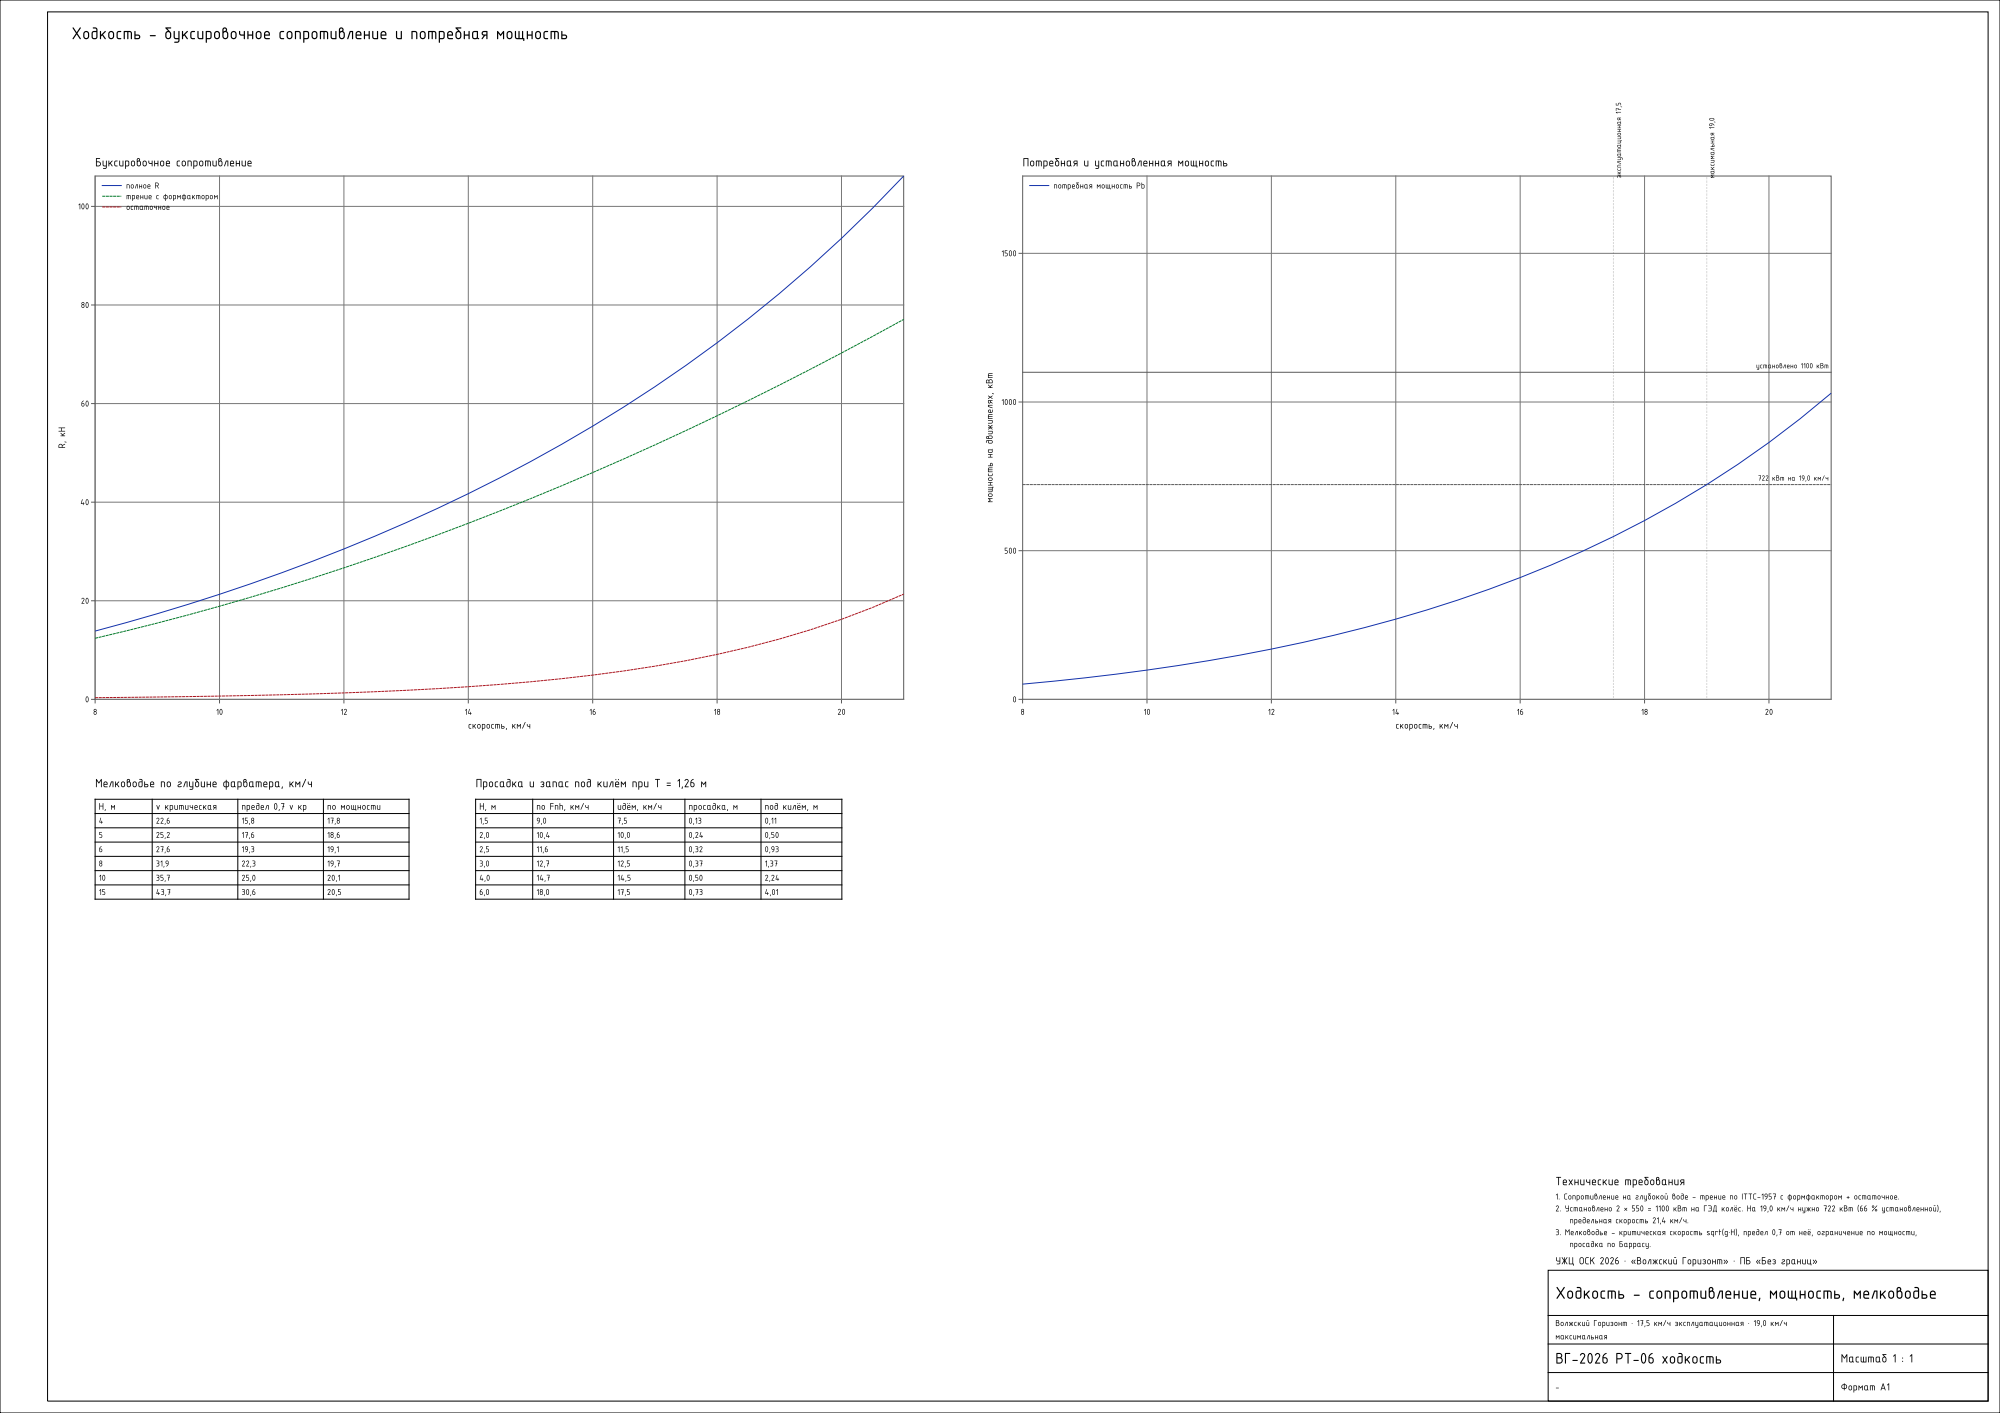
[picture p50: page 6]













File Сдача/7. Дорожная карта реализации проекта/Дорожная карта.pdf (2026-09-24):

Стр. 1

Ид. | Название задачи | ДлительностьНачало
1 График постройки круизного судна "Волжский | Горизонт" | 864 дней | 22.09.2026

2 | 1. Предпроектные работы | 2 дней | 22.09.2026
3 | 1.1. Получение ТЗ от Заказчика | 2 дней | 22.09.2026
4 | 1.2. Проработка ТЗ в ПБ "Без Границ" | 2 дней | 22.09.2026
5 1.3. Анализ текущих мощностей АО | "Адмиралтейские верфи" | 2 дней | 22.09.2026

6 | 2. Маркетинг | 10 дней | 24.09.2026
7 | 2.1. Маркетинговый анализ рынка речных ресурсов 3 дней | | 24.09.2026
8 | 2.2. Разработка стратегии конкурентоспособности | 7 дней | 24.09.2026
9 | 3. Дизайн и проектирование | 90 дней | 24.09.2026
10 3.1. Прототипирование и НИР (расчёты по теории | корабля, ходкости, остойчивости и прочности) | 90 дней | 24.09.2026

11 | 3.2. Эскизирование | 31 дней | 12.11.2026
12 | 3.3. Разработка дизайна | 35 дней | 26.11.2026
13 | 3.4. ОКР (опытно-конструкторская работа) | 40 дней | 26.11.2026
14 4. Согласование технического проекта с Российским | Речным Регистром | 20 дней | 21.01.2027

15 | 5. Экономика и договорная работа | 25 дней | 21.01.2027
16 | 5.1. Расчёт ориентировочной стоимости | 15 дней | 21.01.2027
17 | 5.2. Согласование ОЦ и ТЗ с заказчиком | 5 дней | 11.02.2027
18 | 5.3. Оформление и подписание договора | 5 дней | 18.02.2027
19 6. Составление рабочей конструкторской | документации (схемы систем, чертежи | 116 дней | 21.01.2027

20 | 7. Подготовка производства | 66 дней | 02.07.2027
21 | 7.1. Составление графика строительства | 10 дней | 02.07.2027
22 7.2. Распределение графиков строительства между | ОПЦ | 6 дней | 16.07.2027

23 7.3. Составление и расчёт тех.нарядов согласно | графикам | 15 дней | 26.07.2027

24 | 7.4 Проектирование и изготовление оснастки | 28 дней | 16.08.2027
25 | 7.5. Внедрение производственной системы | 7 дней | 23.09.2027
26 | 8. Материально-техническое обеспечение | 260 дней | 16.07.2027
27 8.1. Формирование спецификаций и заявок на | закупку | 30 дней | 16.07.2027

28 8.2. Заключение договоров с поставщиками | (включая длинноцикловые позиции: ГДГ, ГЭД, колёса с приводами) | 45 дней | 30.07.2027

29 8.3. Поставка металла и материалов, входной | контроль качества | 45 дней | 01.10.2027

30 8.4 Поставка длинноцикловых позиций: ГДГ, ГЭД, | колёса с приводами, батарея | 205 дней | 01.10.2027

31 | 9. Персонал | 104 дней | 16.07.2027
32 | 9.1. Разработка системы оплаты труда и мотивации 49 дней | | 16.07.2027
33 | 9.2. Формирование проектной группы | 43 дней | 16.08.2027
34 | 9.3. Обучение персонала | 40 дней | 14.10.2027
35 | 10. Постройка проекта | 257 дней | 14.10.2027
36 | 10.1. Корпусообработка, изготовление деталей | 183 дней | 14.10.2027
37 | 10.2. Сборка и сварка секций и блоков | 183 дней | 14.10.2027

Ид. | Название задачи | ДлительностьНачало
38 | 10.3. Изготовление изделий МСЧ | 257 дней | 14.10.2027 | 08.12.27 Закладка киля
39 | Закладка киля | 0 дней | 08.12.2027
40 | 10.4. Выполнение работ на стапеле | 169 дней | 03.02.2028
41 | 10.4.1 Формирование корпуса на стапеле | 159 дней | 03.02.2028
42 | 10.4.2 Монтаж механизмов | 94 дней | 18.05.2028
43 | 10.4.3 Монтаж трудоброводов | 94 дней | 18.05.2028
44 | Спуск на воду | 0 дней | 12.09.2028
45 11. Выполнение работ на достроечной набережной | (монтаж оборудования и систем, отделочные работы), пуско-наладочные работы | 245 дней | 13.09.2028
46 | 12. Проведение швартовных испытаний | 14 дней | 22.08.2029
47 13. Устранение ошибок по результатам швартовных | испытаний | 18 дней | 11.09.2029
48 | 14. Проведение заводских ходовых испытаний | 7 дней | 05.10.2029
49 15. Устранение ошибок по результатам заводских | ходовых испытаний | 28 дней | 16.10.2029
50 Подписание акта об устранении замечаний по | результатам испытаний | 0 дней | 22.11.2029
51 16. Освидетельствование судна РРР (выдача | классификационного свидетельства) | 11 дней | 23.11.2029
52 | 17. Передача заказчику | 25 дней | 10.12.2029
53 17.1. Формирование и подписание акта | сдачи-приёмки выполненных работ | 25 дней | 10.12.2029
54 | Судно передано заказчику | 0 дней | 11.01.2030
55 Сервисное обслуживание и выполнение гарантийных | обязательств | 522 дней | 12.01.2035
56 | Утилизация (после окончания срока эксплуатации) | 365 дней | 12.01.2055

### 12.09.28 Спуск на воду

### 22.11.29 Подписание акта об устранении замечаний по результатам испытаний
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

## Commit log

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2026-09-10 Каюты четырёх категорий на одной модульной сетке
    Блок 3D-дизайна под КЗ УЖЦ ОСК 2026. Каюты не нарисованы по отдельности,
    а нарезаны из одного шага сетки 1.30 м вдоль борта: эконом 2 модуля,
    стандарт 3, бизнес 4, люкс 6. Все площади в свету от 8.50 до 26.18 м²,
    минимум КЗ в 8 м² перекрыт в самой тесной категории.
    Сетка выведена от того, что команда не выбирает: камера шлюза ЕГС задаёт
    ширину корпуса,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
    [cabin_business.step, cabin_econom.step, cabin_lux.step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]
2026-09-10 Судно целиком: корпус, надстройка, палубы, взрыв-схема
    Корпус построен лофтом по таблице шпангоутов с плоским днищем в
    цилиндрической вставке и подъёмом к оконечностям — отсюда наклонный
    форштевень и подзор кормы под винты. Водоизмещение 6253 т и коэффициент
    общей полноты 0.836 считаются по геометрии: подводная часть отсекается
    плоскостью осадки и меряется её объём, а не берётся по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
    [hull.step, vessel.step, vessel_exploded.step]
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2026-09-10 Каюта для маломобильных, обтекаемые обводы, техническая палуба
    Каюта для маломобильных закрывает отдельное требование КЗ и проверяется
    геометрией, а не декларацией: свободная площадь палубы эродируется на
    радиус разворота, и если что-то остаётся, круг 1500 мм в каюту вписан.
    На четырёх модулях он не вписывался ни при какой расстановке, поэтому
    категория занимает пять. Санблок без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
    [cabin_accessible.step, hull.step, vessel.step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]
2026-09-10 Аудит модели, поперечная схема и начинка палуб
    Написан scripts/audit_model.py: проверяет геометрией то, что глазами не
    ловится. Детали за обводом корпуса считаются по вершинам, а не по
    габаритной коробке — у панели, развёрнутой по обводу, коробка много шире
    самой панели, и проверка по коробке объявляла нарушителем каждый второй
    поручень. Опорой считается любая деталь под ногами, а не только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
    [deck_middle.step, vessel.step, vessel_cutaway.step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]
2026-09-10 Мебель общественных зон в 3D
    Добавлена библиотека мебели общественных помещений: обеденные модули,
    барные стойки, кресла конференц-зала, тренажёры, шезлонги, бассейн,
    стеллажи, дорожки боулинга, бильярд, ресепшн, камбузное оборудование,
    койки экипажа, главные двигатели, цистерны. Детализация средняя —
    узнаваемый силуэт и правильный габарит, по шагу расстановки считается
    вместим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
    [deck_main.step, deck_middle.step, vessel.step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]
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2026-09-10 Судовые системы, трапы, современная отделка
    Лежаки на солнечной палубе висели в воздухе: раскладка начинала зону
    шезлонгов на 17-м метре, а сама палуба — с 24-го. Причина была не в
    лежаках, а в том, что границы палуб жили в двух местах — геометрия в
    lib.vessel, раскладка в lib.arrangement — и разошлись. Границы сведены в
    ship.DECK_SHAPE, раскладка читает их оттуда.
    Судовые системы обозначены блоками с под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
    [deck_main.step, deck_middle.step, vessel.step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]
2026-09-10 Чистый обвод, карнизы, ресторан зонами
    Модель впервые проходит аудит без единой детали за обводом корпуса.
    Правки лееров и стеклянных ограждений из прошлого захода на деле не
    применились: в vessel.py остались старые леерные стойки и мёртвая ветка
    «if False else []». Участок переписан начисто — стеклянные ограждения по
    контуру на главной и солнечной палубах, дубликаты убраны.
    Ключевое испр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
    [deck_main.step, deck_middle.step, vessel.step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]
2026-09-10 Рендер помещения и правки по его результатам
    Добавлена модель отдельного зала (src/room_restaurant.py) и скрипт
    интерьерных видов. Зал вырезается из главной палубы по границам зоны, а
    борта сшиваются поперечными отрезками: простой фильтр полного контура по
    длине замыкал правый борт с левым через нос, и вместо зала выходил клин.
    Интерьерный рендер сразу показал то, чего не видно на плане: ба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
    [deck_main.step, room_restaurant.step, vessel.step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]
2026-09-10 Обход с уровня глаз и правки, которые он вскрыл
    Виды от первого лица снимаются камерой, поставленной ТОЧКОЙ в координатах
    судна (scripts/walkthrough.py), а не пресетом: пресет кадрирует всю сборку,
    и 141-метровое судно превращает любой вид изнутри в общий план. Глаз на
    1690 мм — мужчина ростом 1800 мм; рядом на палубах стоят фигуры того же и
    большего роста (src/lib/people.py, отдельная модель src/vessel_walk.py —
    в с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
    [deck_main.step, deck_middle.step, room_restaurant.step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]
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2026-09-15 «Волжский Горизонт»: полная модель, материал и сверка с описанием
    Новое судно по описанию Алексея, собрано с нуля в Blender:
    139.0 x 16.5 x 2.8, четыре закрытых яруса и солнечная палуба на крыше,
    106 пассажирских кают на 212 мест, 31 каюта экипажа на 57 мест.
    Три решения, определившие компоновку:
    - четвёртый закрытый ярус 9.80..12.60 — программа помещений в три палубы
    не влезает, а крыша яруса в 9.8 м над в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
    [gorizont.blend, vessel_wip.blend]
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2026-09-17 Продольный разрез в DXF получил таблицу ярусов
    Лист был наполовину пустой: добавлена экспликация шести ярусов с высотами,
    площадями, числом мест и основными помещениями. Все одиннадцать DXF
    проверены аудитом ezdxf: ноль ошибок, ноль исправлений.
    [VG-2026.15.01_knica_sponsona.dxf, ВГ-2026_машинное_отделение.dxf, ВГ-2026_поперечное_сечение.dxf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]
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2026-09-20 Вся графика пересобрана под исправленную модель
    Семь интерьеров, девять видов, шесть планов, продольный разрез, судовые
    системы, доступность, набор корпуса, взрыв-модель, модельный ряд, лист
    проекта и сводка.
    Финальный аудит: пересечений 0, за обводом 0, за надстройкой 0, висящих
    кусков 0, кресел на ходулях 0, стульев спиной к столу 0. Дыр в ограждении
    18 точек по одному-двум лучам из 72 —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
    [gorizont.blend]
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2026-09-22 Дорожная карта: редакция Лены от 22.09.2026 как база, четыре нестыковки исправлены
    gorizont_build.ЛЕНА — её вторая редакция как есть: ид задач, даты начала и
    длительности в рабочих днях MS Project; в ней учтены наши замечания к первой
    редакции (РКД, Регистр, МТО, персонал после договора, закладка киля,
    освидетельствование). Исправлено сразу, с записью «что было у Лены и почему
    иначе» в поле задачи: за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
2026-09-23 Карта постройки - редакция 4 Лены (MS Project); рисунки в записке с подписями «Рисунок N»
    - gorizont_build.ЛЕНА по редакции 4 от 23.09.2026: 56 задач, договор 24.02.2027, закладка 08.12.2027,
    спуск 12.09.2028, ходовые 05.10.2029, передача 11.01.2030; исправлена опечатка - сервис с 12.01.2030.
    Проверка «Сдача в навигацию» заменена на «Перегон к открытию навигации», 13 из 13. Риск ледохода - осенний.
    - Вид карты не меняется: в записке и док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
2026-09-23 Все схемы и графики в простом виде: диаграммы как из Excel, схемы как из Word
    - lib/plain.py - общий стиль: excel() (Calibri 200 dpi, цвета Office, легенда снизу, десятичная запятая, рамка области),
    word() (Times New Roman, белые рамки, чёрные линии, «под проект» пунктиром), сохранить() через temp + os.replace
    - без заголовков, штампов, тёмных фонов, плашек и колонок текста: 01 колесо, 04 и 04а маршрут, 05 солнечная палуба,
    06 модули, мод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
2026-09-24 Экономика судна по расчёту экономиста: блок 6, подбор, оплата и обучение, приложение Б в Excel
    - gorizont_economy: калькуляция головного судна по статьям верфи и годам 2027…2029, материалы по массе
    корпуса D36 и надстройки АМг5 с КИМ 0,85, ПКИ по ТКП и фундаменты-замки по себестоимости узла,
    ФОТ по нормо-часам с разбивкой по дорожной карте, ОПР и ОХР из штата АУП и ИТР, коммерческие
    - исправлено в исход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
    [ВГ-2026_46_00_СБ.dwg, ВГ-2026_46_01-МД_модель.dwg, ВГ-2026_46_01-СЯ1_ящик_стержневой.dwg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]
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
